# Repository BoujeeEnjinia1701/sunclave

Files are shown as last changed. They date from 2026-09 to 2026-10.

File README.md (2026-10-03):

# SunClave

     

**Area:** BioMedical · **TRL:** 3 of 9 (proof of concept on paper) · **Value-engineering target:** USD 450 (estimated cost USD 528) · **Difficulty:** 3 of 5

Solar concentrator that heats a modified pressure-cooker autoclave, with a calibrated temperature, pressure and time logger that records every cycle.

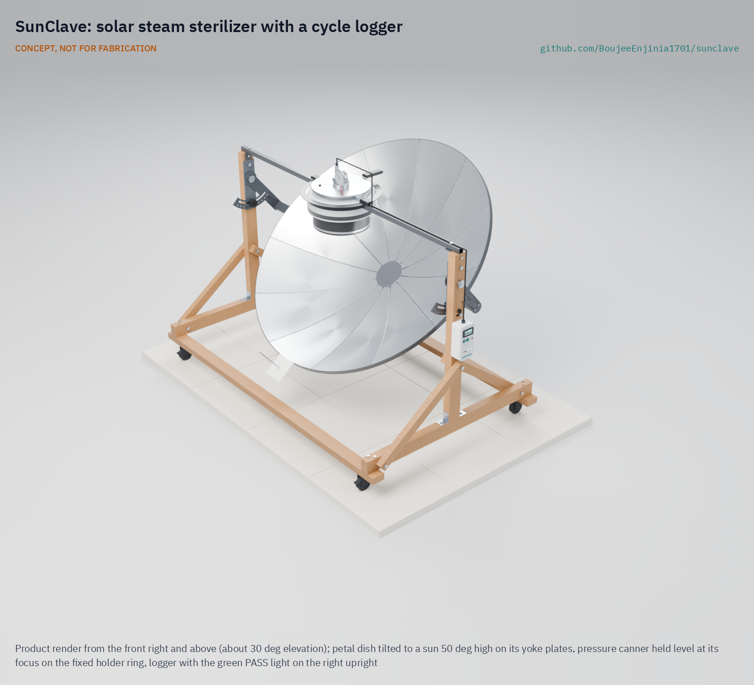
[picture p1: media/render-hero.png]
SunClave: solar steam sterilizer with a cycle logger, product render


[Exploded render](media/render-exploded.png) · [Detail render](media/render-detail.png) · [Interactive 3D model](media/viewer.html) · [Concept blueprint (PDF)](media/concept-blueprint.pdf) · [General arrangement SCL-DWG-001 (PDF)](cad/drawings/SCL-DWG-001.pdf) · [Prototype build plan](docs/05-build-plan.md) · [Design decisions](docs/06-design-decisions.md) · [Calculation note](docs/04-calcs/01-sizing.md) · [Review note](docs/REVIEW.md)

## Concept rationale

A pressure cooker already reaches autoclave conditions, and a 1.4 m solar dish of the kind used for cooking already delivers several hundred watts of heat to a pot. What clinics without power lack is not only the heat but proof that each load was treated, so SunClave pairs a household cooker at the focus of a petal dish with a small logger that checks for saturated steam and times the hold. The cooker stays level while the dish tilts around it, and the operator aims by a shadow, so nobody looks into the focus.

The design is open and garage-buildable because the people who would maintain it are district workshops and biomedical technicians, not a manufacturer's service network. Every structural part is bent flat bar, timber and aluminum sheet joined with bolts and rivets, the only bought pressure part is a commercially rated cooker, and the logger uses common modules. Publishing the geometry, the calculations and the logger's pass criteria lets anyone check the safety case before building one.

## Burning platform

The World Health Organization estimates that close to 1 billion people in low- and lower-middle-income countries are served by health facilities without reliable electricity; in sub-Saharan Africa about 15 % of facilities have no electricity at all and only about 40 % have a reliable supply ([WHO, 2023](https://www.who.int/news-room/fact-sheets/detail/electricity-in-health-care-facilities)). An electric autoclave is out of reach in those facilities, so instruments are boiled, soaked or steamed without any record of the conditions reached.

The consequences show up in infection rates. WHO reports that in low- and middle-income countries 11 % of patients who undergo surgery are infected in the process, and that in Africa up to 20 % of women who have a caesarean section contract a wound infection ([WHO, surgical site infections](https://www.who.int/news-room/questions-and-answers/item/surgical-site-infections)). Instrument reprocessing is one of several links in that chain, and the one that heat plus a record can address directly.

## Where it could be used

As a research and educational prototype, SunClave is a platform for studying off-grid steam sterilization and cycle records; it is not a medical device.

### By industry

| Industry | Use |
| --- | --- |
| Rural primary health care | Research on solar steam cycles and per-load records at health posts without grid power |
| Maternity and midwifery programs | Studying how delivery kits could be reprocessed and logged during daylight |
| Dental and eye outreach | Temporary camps that need instrument reprocessing for a few days at a site |
| Humanitarian and disaster response | Field clinics after grid failures, alongside the stove backup the design already allows |
| Veterinary field practice | Rural livestock and animal-health services reprocessing surgical instruments |
| Biomedical engineering education | Teaching optics, steam thermodynamics, pressure safety and measurement uncertainty on one open design |

### By country or region

| Country or region | Why it matters there |
| --- | --- |
| Kenya and the East African highlands | Highland facilities sit above sea level, where a 103.4 kPa cooker falls short of 121 °C and the logger extends the hold; in sub-Saharan Africa only about 40 % of facilities have reliable electricity ([WHO](https://www.who.int/news-room/fact-sheets/detail/electricity-in-health-care-facilities)) |
| Nepal | Hill and mountain health posts combine altitude with weak grids; about 12 % of health facilities in South Asia have no electricity ([WHO](https://www.who.int/news-room/fact-sheets/detail/electricity-in-health-care-facilities)) |
| Niger (Sahel) | Daily solar irradiation averages about 7 kWh/m², and in 2018 only about 13 % of the population, and about 1 % in rural areas, had access to electricity ([African Development Bank, Desert to Power roadmap for Niger, 2020](https://www.afdb.org/sites/default/files/2024/08/23/desert-to-power_dtp_roadmap_for_niger_en_oct2020.pdf)) |
| Peru and Bolivia (Andes) | In Latin America and the Caribbean about 8 % of health facilities have no electricity and only about 72 % have a reliable supply ([WHO](https://www.who.int/news-room/fact-sheets/detail/electricity-in-health-care-facilities)); highland sites would test the extended-hold method at high altitude |
| Puerto Rico, United States | A high-income case: after Hurricanes Irma and Maria in 2017 it took about 11 months to restore power to all customers in Puerto Rico ([US Government Accountability Office, GAO-19-296](https://www.gao.gov/products/gao-19-296)), a reminder that grid failure also reaches health systems in wealthy economies |

## What sparked the idea

The starting point was two French inventions a year apart. At the 1878 Paris Exposition, Augustin Mouchot won a gold medal for what was then the world's largest parabolic solar collector, which focused sunlight onto a blackened copper vessel of water to raise steam ([Bureau International des Expositions](https://bureauinternationaldesexpositions.bie-paris.org/site/en/latest/blog/entry/expo-1878-paris-the-revelation-of-sun-power)). In 1879 Charles Chamberland, working with Louis Pasteur, introduced the autoclave for medical and scientific use, a descendant of Denis Papin's 1679 high-pressure cooker ([Smithsonian National Museum of American History](https://americanhistory.si.edu/collections/object/nmah_536)). SunClave puts the two back together: a blackened vessel at the focus of a parabolic dish, where the vessel is Papin's pressure cooker doing Chamberland's job, with a logger added so every cycle leaves a record.

## Problem

Rural clinics lack power to sterilize instruments in an autoclave. Close to 1 billion people are served by health facilities with no or unreliable electricity, and where instruments are steamed in a pressure cooker on a fire, nothing records whether each load reached sterilizing conditions. Full problem statement: [docs/01-problem.md](docs/01-problem.md)

## Concept

A 1.4 m parabolic dish of aluminum petals focuses sunlight onto the blackened base of a pressure canner of about 12 L held level at the focus while the dish tilts around it. A cycle logger reads a Pt100 probe in the load zone and an absolute pressure transducer, checks that the chamber holds saturated steam, times the hold and shows PASS or FAIL for each cycle. The TRL 3 calculation note puts about 660 W into the canner at 700 W/m² of direct sun, about 81 min from a cold start to the end of a 30 min hold, and about four cycles on a clear day. Value-engineering target: USD 450. Estimated cost of the constructable design: USD 528 (USD 78 over the target). A 103.4 kPa (15 psi) canner reaches 121 °C only at sea level, so above it the logger extends the hold, records the real temperature and reminds the operator to trim the dish to save water. With Amish's decisions of 2026-09-25 (retarget every 12 min, a 45 kg limit, the whole vessel treated as a marked hot zone, four locking castors and a 0 to 300 kPa transducer), no requirement is missed on paper; cycle time and wind stability remain at risk. Details are in the [review note](docs/REVIEW.md).

Full design precis: [docs/02-concept.md](docs/02-concept.md) · Requirements: [docs/03-requirements.md](docs/03-requirements.md)

## Key components

- 1.4 m petal dish on two yoke plates turning on fixed axles, with two tilt locks and a back-up drop pin, in a bolted timber stand on four locking castors
- Aluminium pressure canner of about 12 L hanging by its handles from a fixed holder ring, with its weighted regulator, factory gauge and relief valve and an insulated jacket; its lid is never drilled
- Pt100 load-zone probe and absolute pressure transducer on a small adapter plate in the lid's vent-pipe hole
- Cycle logger on a USB power bank with pass or fail per cycle, and retarget and trim reminders
- Shadow gnomon for aiming without looking at the sun
- Goggles, a parking cover and keep-out marking for the hot zone

The priced bill of materials is in [bom/bom.csv](bom/bom.csv); the parametric model is `cad/src/model.py`.

## Building the prototype

The design is constructable: every part can be cut, bent, drilled or bought, and every joint is bolted or riveted, with nothing welded. The [prototype build plan](docs/05-build-plan.md) takes a maker through 18 made components and 19 assembly steps, each with a picture drawn from the model, and stops before the cooker is ever pressurised. The changes that made the concept buildable are recorded in [SCL-DDR-003](docs/decisions/0003-design-for-construction.md), and every decision is indexed in the [design decisions register](docs/06-design-decisions.md).

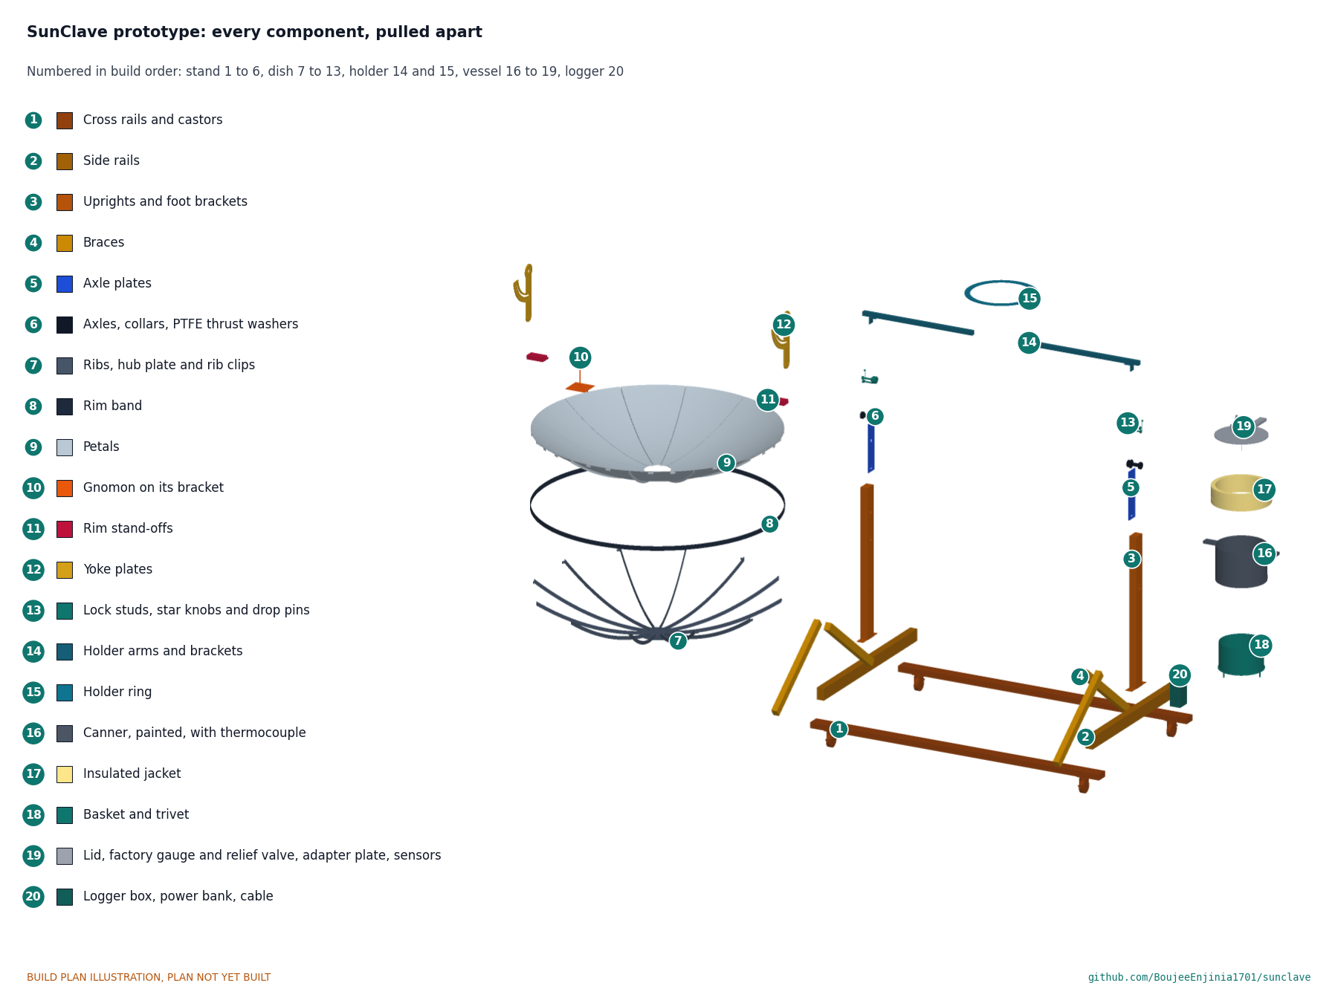
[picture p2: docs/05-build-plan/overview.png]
SunClave prototype: every component, pulled apart and numbered in build order


## Safety

> This is a research and educational prototype. It is not a medical device, has not been cleared or approved by any regulator, and must not be used to diagnose, treat or monitor any person. This design involves concentrated sunlight that can burn skin and eyes and start fires, and heat and pressurized steam. Keep operating pressure and water volume below local boiler and pressure vessel code thresholds, fit a certified relief valve, do not drill the cooker lid (use a pressure canner with factory-fitted gauge and relief valve), and never operate it unattended.

## Repository layout

| Folder | Contents |
| --- | --- |
| `docs/` | Problem, concept, requirements, calculations and design decisions |
| `cad/src/` | build123d Python source, the source of truth for all geometry |
| `cad/step/`, `cad/stl/` | Exported models for FreeCAD, other CAD tools and printing |
| `cad/drawings/` | 2D sketches and dimensioned drawings |
| `bom/` | Bill of materials |
| `electronics/` | KiCad schematics and PCB layouts |
| `firmware/` | Microcontroller code |
| `media/` | Renders, perspectives and photos |
| `build-log/` | Dated prototyping notes |

## Documentation

Controlled documents follow the portfolio [documentation standard](.kit/STANDARDS.md). Each carries a document ID (SCL-PRC-001 for the precis), a version and a revision history. Branded PDFs are built with `python .kit/render.py` and attached to GitHub Releases when a document is tagged, for example `SCL-PRC-001/v1.0`.

## Credits

Designed by Amish Chadha, with contributions from Dr. Geeti Chadha. See [CONTRIBUTORS.md](CONTRIBUTORS.md) for roles. To cite this design, use [CITATION.cff](CITATION.cff) (GitHub shows it as "Cite this repository").

AI assistance (Claude) was used to accelerate concept renders, prototype documentation and first-pass sizing calculations. Design direction and all decisions are Amish Chadha's, recorded in this repository's decision records (`docs/decisions/`).

## Licenses

- **Hardware** (CAD, drawings, BOM, electronics): [CERN-OHL-S v2](LICENSE)
- **Software** (firmware, scripts, notebooks): [MIT](LICENSE-SOFTWARE)

A project of the [Design Molecule](https://designmolecule.com) lab.

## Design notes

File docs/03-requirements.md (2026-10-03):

---
doc_id: SCL-REQ-001
title: SunClave requirements
project: SunClave
doc_type: Requirements
version: "0.8"
status: Draft
date: '2026-10-03'
author: Amish Chadha
license: CERN-OHL-S-2.0
revisions:
- version: "0.1"
  date: '2026-09-24'
  author: Amish Chadha
  change: Initial scaffold
- version: "0.2"
  date: '2026-09-25'
  author: Amish Chadha
  change: First measurable requirements for TRL 2, with design case and status against the concept estimates
- version: "0.3"
  date: '2026-09-25'
  author: Amish Chadha
  change: Apply SCL-DDR-001 (R1, R13 and R17 redefined, design case completed) and replace the status column with the TRL 3 results of SCL-CAL-001
- version: "0.4"
  date: '2026-09-25'
  author: Amish Chadha
  change: Recommendations accepted by Amish (DDR-002)
- version: "0.5"
  date: '2026-10-01'
  author: Amish Chadha
  change: Status from SCL-CAL-001 v0.3 for the constructable design (SCL-DDR-003); R17 reported against the value-engineering target
- version: "0.6"
  date: '2026-10-02'
  author: Amish Chadha
  change: "R15 note: back-up drop pin decided on 2026-10-02 (SCL-DEC-001); no requirement changed status"
- version: "0.7"
  date: '2026-10-02'
  author: Amish Chadha
  change: "Status from SCL-CAL-001 v0.4 (canner, adapter plate and drop pins carried into the design); R8 wording for the factory relief valve; no requirement changed status"
- version: "0.8"
  date: '2026-10-03'
  author: Amish Chadha
  change: "R16 mass margin of 0.2 kg accepted by Amish on 2026-10-03; weighed at TRL 4 with a canner of 5.0 kg or less"
---

# SunClave requirements

These requirements are checked by calculation in SCL-CAL-001 at TRL 3. Targets are still proposals, not yet validated with users, and will be revised after co-design sessions (see SCL-PRB-001). R1, R13 and R17 were restated on 2026-09-25 to apply Amish's decisions in SCL-DDR-001 (altitude option B, and the budget cuts and $450 budget). In v0.4, R10, R11, R14 and R16 are restated or relaxed and R12's design basis changed, applying Amish's acceptance of the recommendations in SCL-DDR-002. The status column gives the TRL 3 result from SCL-CAL-001 v0.3, for the constructable design of SCL-DDR-003; every value is a paper estimate. The cost target in R17 is a value-engineering target (Amish, 2026-10-01), so R17 is reported as over or under it rather than as met or not met.

The **design case** is a clear day with 700 W/m² direct normal irradiance (DNI) and the sun 60° above the horizon, 25 °C ambient, wind 2 m/s (below 3 m/s), a site at sea level, and a load of 2.0 kg of unwrapped or single-wrapped solid stainless instruments in a 0.5 kg basket, with 1.5 L of water in a 12 L aluminum cooker.

> **Safety:** These requirements describe a pressure vessel heated by concentrated sunlight, in a research and educational prototype that is not a medical device. R8 to R11 are safety requirements and take precedence over throughput and cost. A PASS against R1 and R12 records conditions; it does not prove sterility.

| ID | Requirement | Target | Verification (TRL 3 or later) | TRL 3 status (SCL-CAL-001) |
| --- | --- | --- | --- | --- |
| R1 | Sterilizing condition (redefined 2026-09-25, SCL-DDR-001 item 1) | Saturated steam in the load zone for an exposure equal to 20 min (unwrapped) or 30 min (wrapped) at 121 °C, using z = 10 °C for any lower temperature; never below 115 °C nor above 124 °C in normal operation; the real temperature and hold are recorded and a cycle below 121 °C is never labeled 121 °C | Calculation; later instrumented cycles with biological indicators | **Not verifiable at TRL 3.** Met by calculation to 2,400 m (120.95 °C and 30.3 min at sea level; 117.7 °C and 63 min at 1,800 m), but the equivalence needs biological-indicator evidence |
| R2 | Load capacity | Basket at least 250 mm diameter by 150 mm deep; 2.0 kg of solid instruments per cycle (about two delivery kits or four suture kits) | Model check | Met: 250 x 150 mm basket in a 12.3 L cooker, 16 mm above the water |
| R3 | Load type | Solid instruments only, unwrapped or single-wrapped in porous wrap; no lumened, hollow or textile loads | Instructions and design review | Met by definition (decided, SCL-DDR-001 item 9) |
| R4 | Cycle time | Cold start to end of hold in 90 min or less in the design case | Energy calculation; later timed cycles | **At risk:** about 81 min central, 72 to 111 min across scenarios |
| R5 | Daily throughput | 3 or more complete cycles on a clear day (DNI 600 W/m² or more from 09:00 to 15:00 solar time) | Energy calculation | Met: 4 cycles in each case checked; zero on overcast days |
| R6 | Cycle record | Load-zone temperature and chamber pressure logged at 1 s intervals from start to end; cycle ID, date and time, hold duration, minimum hold temperature, equivalent exposure and a pass or fail flag stored for 1,000 or more cycles and shown to the operator at cycle end | Design review; later bench test | Met by design: about 173 kB per cycle, about 23,000 cycles on 4 GB |
| R7 | Measurement accuracy | Temperature within 0.5 °C at 121 °C; pressure within 5 kPa; field check against boiling water at each site | Component datasheets; calibration method at TRL 3 | Met on datasheets: 0.44 °C with a 0.05 % reference resistor; 3 kPa with the 0 to 300 kPa transducer. The field check needs a reference barometer |
| R8 | Pressure safety | Working pressure 103.4 kPa (15 psi) gauge set by the vessel's regulator; a relief valve set at 125 kPa gauge or less (since 2026-10-02 the canner's factory relief valve); the vessel's own overpressure plug retained; vessel rated by its maker for the working pressure | Design review; relief capacity calculation | Met: factory relief valve 5.2 times and vent 2.7 times the worst steam generation if its seat is 4 mm or more; the adapter plate's bore round the probe equals a 5.2 mm hole; lid not drilled; vessel rating and relief valve to confirm for the chosen model |
| R9 | Heat input control | Operator can stop heat input within 10 s by turning the dish off the sun, and the dish is shaded when parked | Design review | Met: below 5 % of power at 15° off the sun; parking cover in the BOM |
| R10 | Boil-dry protection (restated 2026-09-25, SCL-DDR-002 item 17) | At least 0.5 L of water left at the end of a cycle in the design case, and at any altitude to 2,400 m in 1,000 W/m² sun when the operator follows the trimming rule; logger shows a trim reminder whenever the computed hold exceeds 40 min; logger alarm if base temperature exceeds 140 °C | Water budget; later test | Met: 1.26 L left in the design case; with trimming 1.31 L at 1,800 m and 1.28 L at 2,400 m (0.15 L at 1,800 m untrimmed). Depends on the operator following the reminder |
| R11 | Burn and glare protection (restated 2026-09-25, SCL-DDR-002 item 15) | The whole pressure vessel and its fittings are a hot zone, like the lid, reached only after the dish is turned at least 15° off the sun (R9); the focus is reached only through the dish, so no physical guard; parking cover and eye protection supplied; a keep-out marked on the ground around the dish and vessel | Design review | Met by design review: parking cover, two pairs of goggles and keep-out marking in the BOM (items 19 to 21) |
| R12 | Air removal check | Logger flags any hold where measured temperature is more than 2 °C below the saturation temperature for the measured pressure | Calculation; later test with deliberate air leak | Met, narrowly: check uncertainty 0.64 °C with the 0 to 300 kPa transducer (SCL-DDR-002 item 18), 32 % of the threshold; sure to flag about 8 % air |
| R13 | Off-grid logger power (redefined 2026-09-25, SCL-DDR-001 item 2) | Logger runs 3 or more days on its own USB power bank without recharging; the bank recharges from any USB source and does not switch off at the logger's low current | Power budget | Met: about 8.7 days |
| R14 | Tracking effort (relaxed 2026-09-25, SCL-DDR-002 item 13) | Retarget no more often than every 12 min, with a logger reminder at each interval; aim by a shadow gnomon without looking at the sun or the focus | Optics calculation | Met: power stays within 10 % of on-target for about 13 min |
| R15 | Stability | Does not tip in a 10 m/s wind with the dish at any tilt and the cooker loaded | Moment calculation | **At risk:** tipping factor 1.40 at 15° elevation. Four locking castors (SCL-DDR-002 item 16) grip 237 N against 153 N of wind; park the dish face-up in high wind. A back-up drop pin through the yoke plate fans stops a slipping tilt lock (decided 2026-10-02) |
| R16 | Portability and build (relaxed 2026-09-25, SCL-DDR-002 item 14) | Total mass 45 kg or less; separates into pieces of 20 kg or less; built with hand tools, a drill and bolted joints | Mass estimate; model check | Met: about 44.8 kg empty (0.2 kg margin; accepted by Amish on 2026-10-03; weighed at TRL 4 with a canner of 5.0 kg or less, SCL-DDR-003 A1); the bolted stand comes apart, largest piece 15.3 kg |
| R17 | Cost (redefined 2026-09-25, SCL-DDR-001 item 2; a value-engineering target, 2026-10-01) | Parts for one prototype against a value-engineering target of USD 450, validation consumables excluded | Priced BOM (`bom/bom.csv`) | Value-engineering target: USD 450. Estimated cost of the constructable design: USD 528 (USD 78 over the target) |

## Requirements not met or at risk

No requirement is now not met. Before SCL-DDR-002, R11, R14 and R16 were not met; they are met because their targets were restated or relaxed on Amish's acceptance of the recommendations, not because the design improved. R10 and R12 moved from at risk to met through the trimming rule and the 0 to 300 kPa transducer.

- **R4 cycle time (at risk).** Met in the central case (81 min), missed in the unfavourable one (111 min).
- **R15 stability (at risk).** Thin tipping margin at low sun (factor 1.40); the four locking castors now stop the stand rolling.
- **R16 mass (met, thin margin).** 44.8 kg against 45 kg after the constructable design added clips, plates, brackets and bolts, and the canner, adapter plate and drop pins added 0.4 kg; Amish accepted the margin on 2026-10-02 and again on 2026-10-03 ("TIght Margins - i accept the margins"), to be checked by weighing at TRL 4 with a canner of 5.0 kg or less.
- **R17 cost.** USD 78 over the value-engineering target; the cost drivers and savings worth trying are in the design decisions register (SCL-DEC-001).
- **R1 sterilizing condition (not verifiable at TRL 3).** The equivalent-exposure method needs biological indicators.

## Assumptions

- Dish aperture 1.4 m (1.539 m²), focal length 500 mm, reflectance 0.85, slope error 10 mrad, absorber absorptance 0.92; optics by ray trace in SCL-CAL-001.
- Saturated steam temperatures from IAPWS-IF97; ICAO standard atmosphere for ambient pressure with altitude.
- Hold times follow CDC Table 7 and the IARC manual cited in SCL-PRB-001. Equivalent hold at lower temperature uses a z-value of 10 °C, which is a common engineering assumption and not a validated claim.
- "Pass" in R6 means the recorded cycle met R1 and R12. It does not prove sterility; biological and chemical indicators remain the reference.

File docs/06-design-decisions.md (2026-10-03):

---
doc_id: SCL-DEC-001
title: SunClave design decisions register
project: SunClave
doc_type: Design decisions register
version: "0.4"
status: Draft
date: '2026-10-03'
author: Amish Chadha
license: CERN-OHL-S-2.0
revisions:
- version: "0.1"
  date: '2026-10-01'
  author: Amish Chadha
  change: Register opened with the open decisions from the TRL 2 and TRL 3 reviews and the design-for-construction work, items to confirm, value engineering and decisions made
- version: "0.2"
  date: '2026-10-02'
  author: Amish Chadha
  change: Amish approved the recommendations for open decisions 1 to 5 (lid fittings decided; SCL-DDR-003 accepted with a back-up drop pin); moved to decisions made
- version: "0.3"
  date: '2026-10-02'
  author: Amish Chadha
  change: "Canner, adapter plate and drop pins priced and carried into the design; value engineering and items to confirm updated"
- version: "0.4"
  date: '2026-10-03'
  author: Amish Chadha
  change: "Amish accepted the R16 mass margin of 0.2 kg on 2026-10-03, to be weighed at TRL 4 with a canner of 5.0 kg or less; row added to decisions made"
---

# SunClave design decisions register

Every design decision still to be made, and every decision made, in one place. Each decision is argued in full in its decision record under `docs/decisions/`; this register is the index Amish works from. The build plan (`docs/05-build-plan.md`) describes the design as it stands and does not list open decisions.

> **Safety:** SunClave is a research and educational prototype, not a medical device. Decision 1 below is a pressure-safety decision and must be made before the cooker is ever pressurised with the fittings on its lid.

## Open decisions

None. All open decisions were decided on 2026-10-02.

## To confirm when parts are bought

| # | What to confirm | Why it matters | Source |
| --- | --- | --- | --- |
| 1 | The canner's maker's rating for 103.4 kPa, its outside diameter (about 288 mm), its mass with fittings (about 4.8 kg, 5.0 kg at most), and handles whose undersides are about 28 mm below the rim and reach at least 214 mm from the centre | The rating is R8; the handles must rest on the 408 mm holder ring and the jacket must clear its 348 mm hole; the mass margin of R16 is 0.2 kg | SCL-DDR-001 items 4 and 5, SCL-DDR-003 C3 |
| 2 | The reflector sheet takes a 12 mm flange fold without cracking its bright layer | The petals are fixed by riveting through these flanges | SCL-DDR-003 C6 |
| 3 | A 20 x 3 mm bar bends on edge in the plywood jig without buckling (bend one rib first) | If it buckles, the ribs need a heavier bar or a fabricator's rolls | SCL-DDR-003 C6 |
| 4 | Castor mounting height 102 mm and a top-plate hole pattern on a 42 mm square, all four with brakes | Sets the stand height and the drilling of the cross rails | SCL-DDR-003 C5 |
| 5 | The power bank has a low-current (always-on) mode | The logger draws about 72 mA; many banks switch off below 50 to 100 mA | SCL-CAL-001 section 11 |
| 6 | The canner's factory relief valve has a seat of 4 mm or more and a set pressure of 125 kPa gauge or less; the lid's vent-pipe hole and thread, for the adapter plate | R8 relief capacity; the adapter plate is made to fit the canner | SCL-CAL-001 section 8 |
| 7 | The pressure transducer's overpressure rating is 600 kPa or more | It must survive a relief lift | SCL-DDR-002 item 18 |

## Value engineering

Value-engineering target: USD 450 (a hypothetical control target, not a limit). Estimated cost of the constructable design: USD 528 (USD 78 over the target), validation consumables (USD 45) excluded. Main cost drivers and savings worth trying:

- The largest lines are the pressure canner with its gauge and relief valve (USD 100), the reflector petals (USD 75), the cycle logger (USD 66), the timber stand with castors, axles and plates (USD 58) and the adapter plate, gland and probe (USD 45).
- Making the design constructable added USD 57 (from USD 440): the yoke plates, stand-offs and locks (line 3, USD 18 to 30), the stand's axle plates, axles, collars and brackets (line 4, USD 44 to 58), the clips (line 2), the plate ring and brackets (line 5), the larger logger box and plug-in sensor leads (line 14) and more bolts (line 17).
- The decisions of 2026-10-02 added USD 31 (from USD 497): the pressure canner sold with its gauge and relief valve (line 6, USD 55 to 100) in place of the household cooker and the separate gauge and relief valve (lines 8 and 9, USD 35, now supplied with the canner), the vent-stem adapter plate (line 10, USD 30 to 45) and the drop pins and lanyards (line 3, USD 30 to 36).
- Savings worth trying: compare canners sold with a gauge in the target area, since line 6 is now the largest line; have one local cutting shop cut the yoke plates, axle plates, holder ring and hub plate from one sheet of steel (likely cheaper than four separate jobs); price aluminised film on plain 0.5 mm aluminium against bright reflector sheet; buy the logger modules as one combined board; buy bolts in boxes of 50 rather than by the piece.

## Decisions made

| Date | Decision | Decided by | Record |
| --- | --- | --- | --- |
| 2026-09-25 | TRL 2 review items 1 to 4 and 6 to 11: altitude option B, budget cuts with USD 450, pitch wording, 12 L household cooker, level cooker at the focus, petal dish, gnomon aiming, load limits, logger pass criteria, backup heat | Amish: "proceed with all of your recommendations across all batches. Make sure we don't proceed to TRL 4 on any of them." | SCL-DDR-001 |
| 2026-09-25 | Items 13 to 18: retarget every 12 min, 45 kg total, whole vessel a marked hot zone, four locking castors, trimming rule, 0 to 300 kPa transducer | Amish: "i accept all your recommendations, go with them across all repos." | SCL-DDR-002 |
| 2026-09-25 | TRL 4 is on hold for the whole portfolio | Amish: "Make sure we don't proceed to TRL 4 on any of them" | SCL-DDR-001 |
| 2026-09-30 | Make the design physically buildable while drawing the build plan | Amish: "If you are realising that the design cannot be built as per concept - fix the design assumptions to match and be physically feasible as you draw the illustrations." | SCL-DDR-003 (accepted on 2026-10-02, below; was open for review as decision 2) |
| 2026-09-30 | Open decisions are kept in this register, not in the build plan | Amish: "don't log outstanding decisions in this build plan - that is not the place for it." | This register |
| 2026-10-01 | `budget_usd` is a value-engineering target, not a limit | Amish: "the budgets are a hypothethical control target to ensure we are thinking along a value engineering lens." | This register, Value engineering |
| 2026-10-02 | Lid fittings: the maker's lid is not drilled; a pressure canner sold with a factory gauge and relief valve is used, and the probe gland goes on an adapter plate on the vent stem that keeps a bore of 3 mm or more and leaves the overpressure plug untouched; a lid is drilled only with the maker's written approval | Amish: "i approve your recommendations for all 555 open decisions." | SCL-DDR-001, item 5 |
| 2026-10-02 | Design for construction accepted: the changes C1 to C9, as made, with the tilt lock settled under decision 4 | Amish: "i approve your recommendations for all 555 open decisions." | SCL-DDR-003, Table 1 |
| 2026-10-02 | R16 mass margin of 0.6 kg accepted; the prototype is weighed at TRL 4, with the 5 mm yoke plates and lighter holder arms ready | Amish: "i approve your recommendations for all 555 open decisions." | SCL-DDR-003, A1 |
| 2026-10-02 | Tilt lock: the two friction locks are kept for aiming and a drop pin through a row of holes in the fan is added as a back-up stop; the pin is removed only if the TRL 4 slip test shows the locks holding at least twice the 45 N·m worst torque | Amish: "i approve your recommendations for all 555 open decisions." | SCL-DDR-003, A2 |
| 2026-10-02 | First partner to approach: a university biomedical or global health engineering group with an established rural clinic partner in a sunny region below 2,400 m, for example through an Engineering World Health university chapter | Amish: "i approve your recommendations for all 555 open decisions." | SCL-DDR-001, item 12 |
| 2026-10-03 | R16 mass margin of 0.2 kg accepted (about 44.8 kg against 45 kg); the prototype is weighed at TRL 4 with a canner of 5.0 kg or less | Amish: "TIght Margins - i accept the margins" | SCL-REQ-001, R16; SCL-DDR-003, A1; [REVIEW.md](REVIEW.md), session 2026-10-03 |

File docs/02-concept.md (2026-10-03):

---
doc_id: SCL-PRC-001
title: SunClave design precis
project: SunClave
doc_type: Design precis
version: "0.7"
status: Draft
date: '2026-10-02'
author: Amish Chadha
license: CERN-OHL-S-2.0
revisions:
- version: "0.1"
  date: '2026-09-24'
  author: Amish Chadha
  change: Initial scaffold
- version: "0.2"
  date: '2026-09-25'
  author: Amish Chadha
  change: Populate to TRL 2 (architecture, components, first-order numbers, altitude finding, safety, media)
- version: "0.3"
  date: '2026-09-25'
  author: Amish Chadha
  change: Apply SCL-DDR-001 decisions (option B, $450 budget and cuts, vessel, holder, dish, aiming, load limits, pass criteria, backup heat); replace first-order numbers with SCL-CAL-001; TRL 3 model, drawing and media
- version: "0.4"
  date: '2026-09-25'
  author: Amish Chadha
  change: Recommendations accepted by Amish (DDR-002)
- version: "0.5"
  date: '2026-10-01'
  author: Amish Chadha
  change: Constructable design (SCL-DDR-003, draft) and build plan SCL-BLD-001; numbers from SCL-CAL-001 v0.3; cost against the value-engineering target
- version: "0.6"
  date: '2026-10-02'
  author: Amish Chadha
  change: "Decisions of 2026-10-02 carried in: lid fittings (no drilling; pressure canner with factory gauge and relief valve), back-up drop pin, first partner to approach"
- version: "0.7"
  date: '2026-10-02'
  author: Amish Chadha
  change: "Canner, vent-stem adapter plate and drop pins carried into the model, BOM and calculations (SCL-CAL-001 v0.4); components and headline results updated"
---

# SunClave design precis

SunClave is a 1.4 m parabolic dish of aluminum petals that focuses sunlight onto the blackened base of a pressure canner of about 12 L held level at the focus, with a cycle logger that measures temperature in the load zone and chamber pressure and flags each cycle as pass or fail. The TRL 3 calculations (SCL-CAL-001) put about 660 W into the canner on a clear day, enough to go from cold to the end of a 30 min hold in about 81 min and to run about four cycles between 09:00 and 15:00. On 2026-09-25 Amish accepted the recommendations on the TRL 3 findings (SCL-DDR-002): the dish is retargeted every 12 min, the mass limit is 45 kg, the whole vessel is treated as a marked hot zone instead of guarding the focus, all four castors lock, a trimming rule protects the water at altitude and the pressure transducer spans 0 to 300 kPa. On paper no requirement is now missed; cycle time (R4) and wind stability (R15) remain at risk. On 2026-10-01 the design was made constructable (SCL-DDR-003, accepted by Amish on 2026-10-02): every part can be cut, bent, drilled or bought and every joint is bolted or riveted, and the prototype build plan (SCL-BLD-001) shows how. On 2026-10-02 Amish decided the lid fittings (a canner with its own gauge and relief valve, the lid never drilled, the probe and pressure sensor on a vent-stem adapter plate) and a back-up drop pin for the tilt locks; both are now in the model. Value-engineering target: USD 450. Estimated cost of the constructable design: USD 528 (USD 78 over the target).

> **Safety:** SunClave is a research and educational prototype, not a medical device. It has not been cleared or approved by any regulator and must not be relied on to sterilize instruments used on patients. It combines concentrated sunlight that can burn skin, blind and start fires, with a pressure vessel holding steam at about 121 °C (250 °F). See the safety section before building or operating anything.

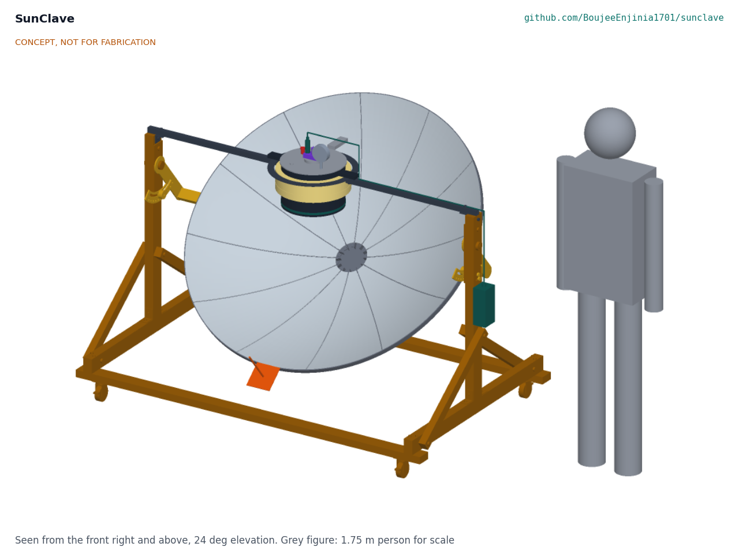
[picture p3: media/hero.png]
Hero render


*Figure 1. SunClave with the dish aimed at a sun 50 degrees above the horizon, and a 1.75 m person for scale. The cooker is held level at the focus on a holder fixed to the stand; the dish and yoke tilt about it.*

## How it works

1. **Load.** The operator puts 1.5 L of water in the cooker, sets cleaned instruments in the basket on its trivet above the water, closes the lid and sets the cooker in the level holder at the focus.
2. **Aim.** The operator unlocks the four castors, turns the stand to face the sun, locks them again and tilts the dish until the shadow of the sighting gnomon falls on the center of its target. Nobody needs to look at the sun or at the bright focus. The logger sounds a reminder every 12 min, and retargeting at that interval keeps the absorbed power within 10 % of on-target (SCL-CAL-001 section 3; decided, SCL-DDR-002 item 13).
3. **Heat and purge air.** About 660 W is absorbed by the blackened base and the black band of wall above it. The water boils, and steam leaves through the open vent for at least 5 min to push air out of the chamber before the weighted regulator is fitted. The logger recognizes this purge as a plateau at the local boiling point.
4. **Pressurize and hold.** With the regulator fitted, pressure rises to 103.4 kPa gauge and the regulator vents the excess. The hold is 20 min (unwrapped) or 30 min (wrapped) at sea level, and longer above it (decided option B): the logger computes the hold that gives the same exposure as 121 °C with z = 10 °C and records the real temperature. Whenever the computed hold exceeds 40 min (every site at 1,000 m and above), the logger shows a trim reminder and the operator trims the dish off the sun until the regulator only just vents, which keeps at least 0.5 L of water in strong sun up to 2,400 m (decided, SCL-DDR-002 item 17).
5. **Record.** Throughout, the logger reads a Pt100 probe in the load zone and an absolute pressure transducer on the lid. It checks that the load-zone temperature matches the saturation temperature for the measured pressure (air left in the chamber shows up as a lower temperature), times the hold, and at the end shows PASS or FAIL with a cycle number to copy into the register.
6. **Cool and unload.** The operator turns the dish away from the sun, fits the parking cover if the session is over, lets the pressure fall to zero on the gauge (about 10 min), removes the regulator, opens the lid and lets the load dry in the residual heat.

On cloudy days the same cooker runs on a wood, charcoal or LPG stove and is logged the same way (decided, SCL-DDR-001 item 11).

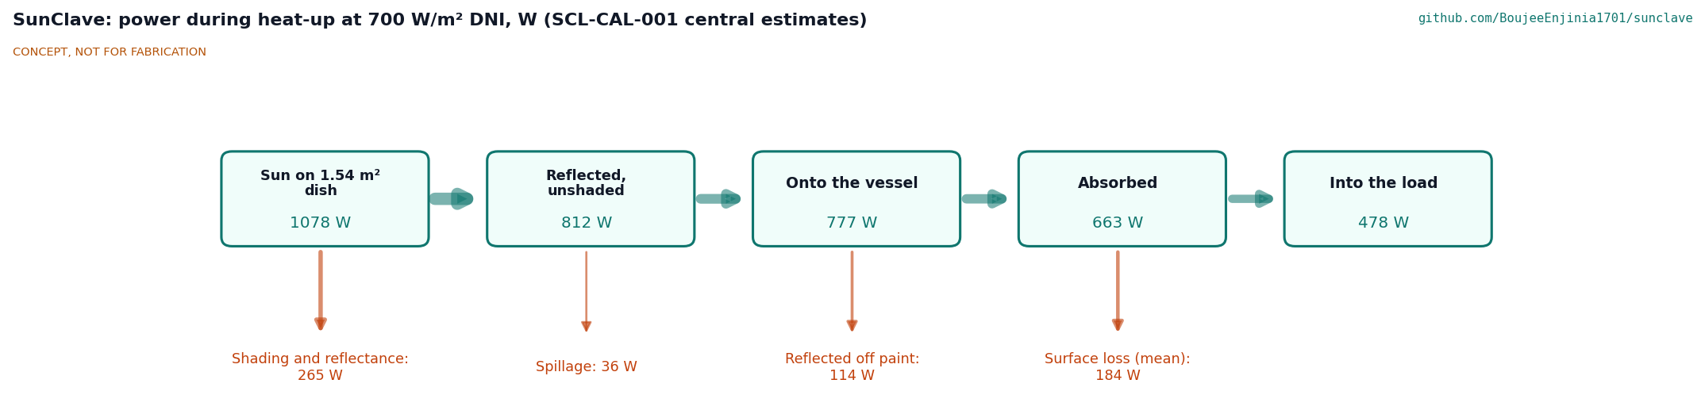
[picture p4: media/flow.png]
Energy flow


*Figure 2. Power flow during heat-up at 700 W/m² DNI and a sun 60° high, central estimates from SCL-CAL-001.*

## Main components

Numbers match the exploded view (Figure 3) and `bom/bom.csv`. The general arrangement is drawing SCL-DWG-001 (`cad/drawings/`), generated from `cad/src/model.py`.

| # | Component | Choice | Notes |
| --- | --- | --- | --- |
| 1 | Reflector | 12 petals of polished aluminum sheet 0.5 mm, 1.4 m aperture, focal length 500 mm | SK14-style petal layout (decided) |
| 2 | Dish ribs, rim, hub and clips | Twelve 20 x 3 mm steel flat-bar ribs bent on edge, 25 x 4 mm rim band, 200 mm hub plate, 24 angle clips; petals riveted through their folded flanges | Holds the petal shape (SCL-DDR-003) |
| 3 | Tilt yoke and locks | A 6 mm steel yoke plate each side turning on a fixed 20 mm axle, joined to the rim band by a tube stand-off; a fan on each plate with a slot that a star knob clamps; a drop pin on a lanyard through a row of holes in each fan as a back-up stop | Dish-axis elevation 15 to 90 degrees; the two locks hold up to about 45 N·m of gravity torque (SCL-DDR-003); if a lock slips the pin stops the dish within 7.5 degrees (decided 2026-10-02) |
| 4 | Stand with castors | Bolted treated timber: cross rails, side rails on edge, uprights to 1.10 m and lapped braces; steel axle plates and axles; four locking castors | Timber decided to save cost (SCL-DDR-001 item 2); all four castors lock (SCL-DDR-002 item 16); azimuth by turning the whole stand |
| 5 | Level pot holder | Flat steel ring the body handles rest on, on two tube arms carried on the upright tops | Fixed to the stand: the loaded canner's centre of mass is about 96 mm above the axis, so a swinging holder would be top-heavy |
| 6 | Pressure canner | Aluminum pressure canner of about 12 L sold with a factory gauge and relief valve, about 280 mm inside diameter x 200 mm deep, 103.4 kPa weighted regulator, overpressure plug; base and lowest 80 mm of wall painted matte black | Vessel decided (SCL-DDR-001 item 4); a canner with factory fittings since 2026-10-02 (item 5) |
| 7 | Lid with regulator | Supplied with item 6; carries items 8 and 9 as supplied and the adapter plate (item 10) in its vent-pipe hole | The lid is not drilled: the factory gauge and relief valve stay as supplied, and the probe gland goes on an adapter plate on the vent stem with a bore of 3 mm or more, overpressure plug untouched (decided 2026-10-02, item 5) |
| 8 | Pressure gauge (factory-fitted) | The canner maker's dial gauge, as supplied | Reads without power, independent of the logger; checked against a reference before use |
| 9 | Relief valve (factory-fitted) | The canner maker's relief valve; set 125 kPa gauge or less and seat 4 mm or more to confirm | Passes 5.2 times the worst steam generation if its seat is 4 mm or more |
| 10 | Vent-stem adapter plate, gland and Pt100 probe | Stainless plate in the lid's vent-pipe hole carrying the maker's vent pipe, the transducer and a compression gland for a 3 mm class A Pt100 into the load zone; 6 mm bore round the probe | Measures where the instruments are; the vent stays as open as a 5.2 mm hole; no new hole in the lid |
| 11 | Insulated jacket | 25 mm mineral wool with aluminized skin on the upper wall | Black band and base stay bare to take the focus |
| 12 | Water charge | 1.5 L per cycle | About 1.26 L left after a central sea-level cycle |
| 13 | Instrument basket and trivet | Stainless basket 250 mm diameter x 150 mm deep on a 40 mm trivet | Resized from 270 x 180 mm, which did not fit a 12 L cooker |
| 14 | Cycle logger | ESP32-class board, Pt100 interface with 0.05 % reference, 16-bit ADC, 0 to 300 kPa absolute pressure transducer, base-edge thermocouple, RTC, microSD, OLED display, buzzer | 1 s logging, pass or fail per cycle, boil-dry alarm, 12 min retarget reminder, trim reminder for holds over 40 min; OLED decided to save cost; transducer span decided (SCL-DDR-002 item 18) |
| 15 | Logger power bank | 10,000 mAh USB bank with a low-current mode, kept in the shaded logger box | About 8.7 days per charge; replaces the panel and cell (decided) |
| 16 | Sighting gnomon | Pin parallel to the dish axis over a target plate, on a bracket outside the rim band | Aiming by shadow (decided) |
| 19 | Eye protection | Two pairs of shade 5 goggles | Added for R11 |
| 20 | Parking cover | Opaque cover for the dish | Added for R9 and R11 |
| 21 | Keep-out marking | Barrier tape and four ground pegs marking 2 m around the dish and vessel | Added for the restated R11 (SCL-DDR-002 item 15) |

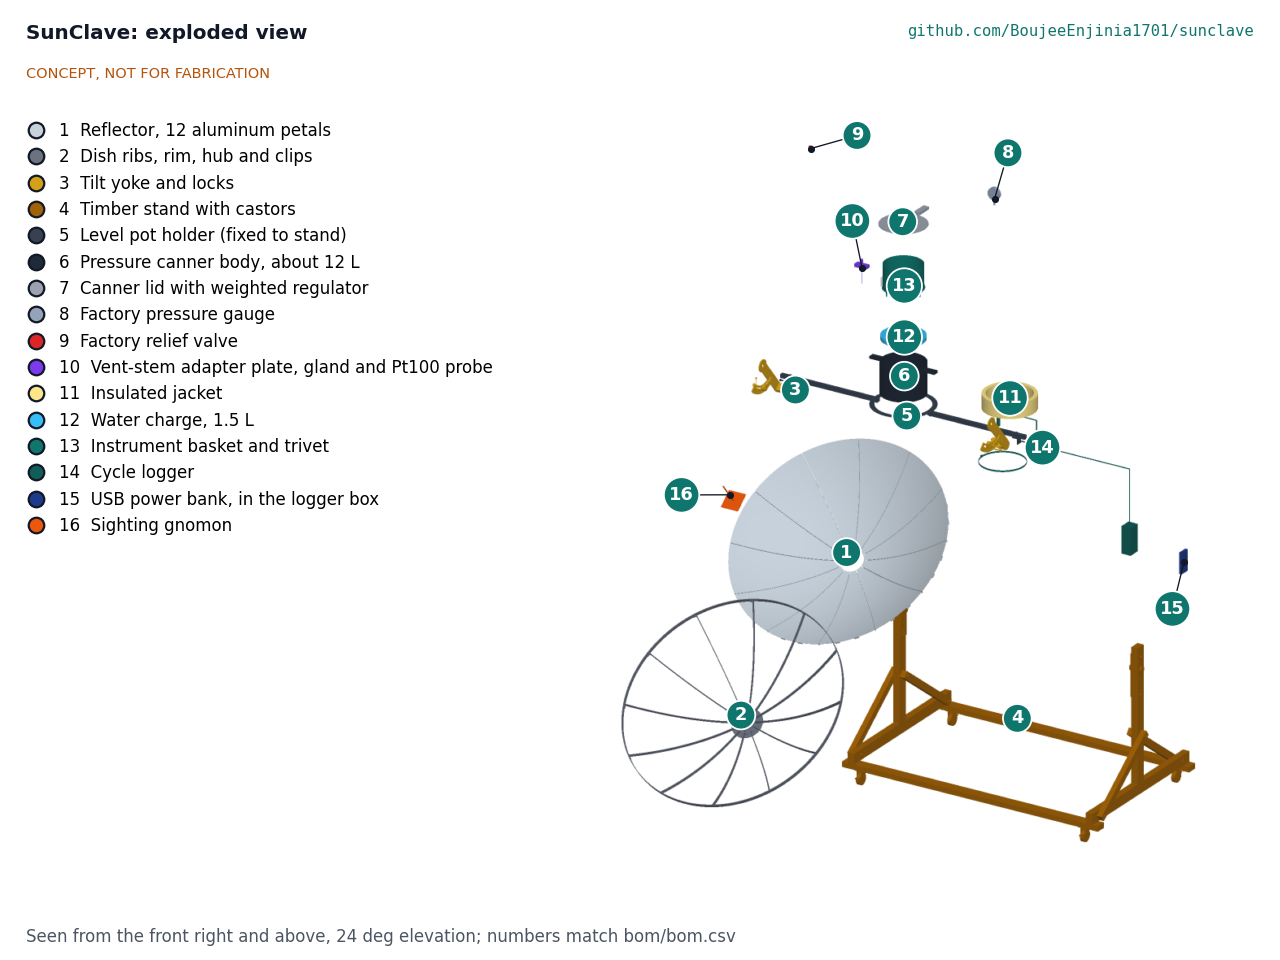
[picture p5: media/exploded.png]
Exploded view


*Figure 3. Exploded view with numbered callouts matching the BOM. The cooker parts are lifted out along the vertical axis. Items 17 to 21 are not modelled.*

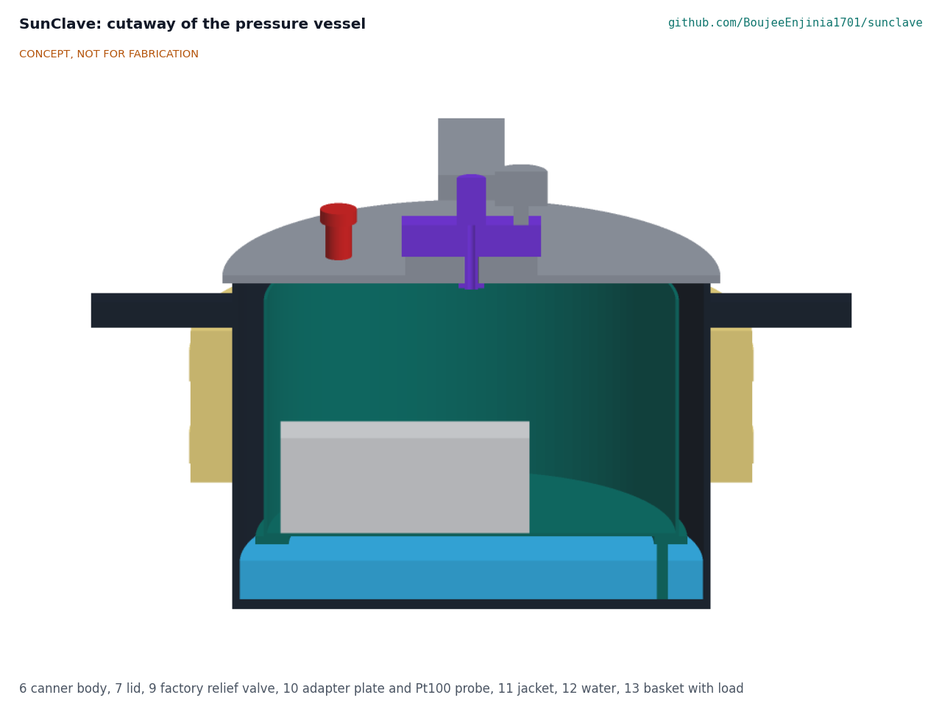
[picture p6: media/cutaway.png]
Cutaway


*Figure 4. Section through the pressure vessel: water below the trivet, the basket and instrument load in steam, the Pt100 probe reaching into the load zone, and the jacket on the upper wall above the bare black band.*

## Key numbers (TRL 3)

All values are paper estimates from SCL-CAL-001 (`python docs/04-calcs/sizing.py`) for the design case in SCL-REQ-001 v0.5: 700 W/m² DNI, sun 60° high, 25 °C, wind 2 m/s, sea level, 2.0 kg of instruments, 1.5 L of water.

*Table 1. Headline results, central case unless a range is given.*

| Quantity | Value | Requirement |
| --- | --- | --- |
| Sun on the aperture | 1,078 W (1.539 m²) | |
| Absorbed by the canner | 663 W on target (575 to 716 W across scenarios); 555 W at 15° sun, 733 W overhead | |
| Peak flux on the base | about 270 kW/m² in the hottest 20 mm cell; mean 11 kW/m² | |
| Heat loss at 121 °C | 395 W (black base and band 245 W, lid 101 W) | |
| Cold start to end of 30 min hold | 81 min (72 to 111 min) | R4 at risk |
| Cycles, 09:00 to 15:00 | 4 | R5 met |
| Water left after a 30 min hold | 1.26 L; with the trimming rule 1.31 L at 1,800 m in strong sun (0.15 L untrimmed) | R10 met (restated) |
| Steam temperature at 103.4 kPa gauge | 120.95 °C at sea level; 117.7 °C at 1,800 m (hold 63 min) | R1 not verifiable at TRL 3 |
| Temperature and pressure accuracy | 0.44 °C; 3 kPa | R7 met |
| Air-removal check uncertainty | 0.64 °C against a 2 °C threshold (0 to 300 kPa transducer) | R12 met, narrowly |
| Retarget interval for 90 % of on-target power | about 13 min, against a 12 min target | R14 met (relaxed) |
| Relief valve capacity | 5.2 times the worst steam generation | R8 met |
| Tipping factor at 10 m/s | 1.40 at 15° sun; four locked castors grip 237 N against 153 N | R15 at risk |
| Mass, empty | 44.8 kg against 45 kg; largest piece 15.3 kg | R16 met (relaxed), thin margin |
| Logger autonomy | 8.7 days | R13 met |
| Parts cost | USD 528 against a USD 450 value-engineering target (USD 78 over) | R17 reported against the target |

### Altitude and sterilizing temperature

A weighted regulator holds a fixed pressure **above ambient**, so the steam temperature falls with altitude. Under the decided option B the logger extends the hold to give the same exposure as 121 °C with z = 10 °C, and records the real temperature.

*Table 2. Steam temperature and extended hold with altitude (IAPWS-IF97, standard atmosphere).*

| Altitude | Ambient pressure | Steam temperature at 103.4 kPa gauge | Gauge pressure needed for 121 °C | Hold for 20 / 30 min at 121 °C (z = 10 °C, not validated) |
| --- | --- | --- | --- | --- |
| 0 m | 101.3 kPa | 120.95 °C | 103.7 kPa | 20 / 30 min |
| 500 m | 95.5 kPa | 120.03 °C | 109.6 kPa | 25 / 37 min |
| 1,000 m | 89.9 kPa | 119.13 °C | 115.2 kPa | 31 / 46 min |
| 1,500 m | 84.6 kPa | 118.26 °C | 120.5 kPa | 38 / 56 min |
| 1,800 m | 81.5 kPa | 117.75 °C | 123.5 kPa | 42 / 63 min |
| 2,400 m | 75.6 kPa | 116.74 °C | 129.4 kPa | 53 / 80 min |

The TRL 2 version of this table gave 121.1 °C at sea level and a 300 m limit; the IAPWS-IF97 line gives 120.95 °C, so 121 °C holds only at sea level. A maker-rated vessel of about 130 kPa gauge (option A) would reach 121 °C to about 2,400 m and remains worth searching for.

## Design choices

Decided by Amish on 2026-09-25 (SCL-DDR-001): option B for altitude; the budget cuts and a $450 budget; the pitch wording; the household 12 L aluminum cooker; the level cooker at the focus with the dish tilting about it; the locally built petal dish; manual aiming by gnomon; solid, unwrapped or single-wrapped loads only; the logger pass criteria (purge plateau of 5 min or more, hold temperature and equivalent time met, and measured temperature within 2 °C of saturation throughout the hold); and backup heat on a stove.

Decided by Amish on 2026-09-25, going with the recommendation (SCL-DDR-002): R14 relaxed to retargeting every 12 min with a logger reminder (item 13); R16 relaxed to 45 kg in total with the 20 kg piece limit kept (item 14); R11 restated so the whole vessel and its fittings are a hot zone, with no physical guard, relying on turning the dish off the sun, the parking cover, goggles and a marked keep-out (item 15); four locking castors and a rule to park the dish face-up in high wind (item 16); a trimming rule with a logger trim reminder (item 17); and a 0 to 300 kPa absolute transducer (item 18).

Decided by Amish on 2026-10-02 (SCL-DEC-001):

- **Item 5: mounting the lid fittings.** Do not drill the maker's lid. Use a pressure canner sold with a factory gauge and relief valve, and carry the probe gland on an adapter plate on the vent stem that keeps a bore of 3 mm or more and leaves the overpressure plug untouched; drill a lid only with the maker's written approval. A drilled lid has no known rating; factory ports keep the maker's rating, and the relief and vent capacity calculation (SCL-CAL-001 section 8) holds for both.
- **Item 12:** the first partner to approach is a university biomedical or global health engineering group with an established rural clinic partner in a sunny region below 2,400 m, for example through an Engineering World Health university chapter. Not yet agreed.
- **Tilt lock (SCL-DDR-003, A2):** the two friction locks are kept for aiming, with a drop pin through a row of holes in the fan as a back-up stop.

## Safety

> **Safety:** SunClave concentrates sunlight to a few hundred times normal intensity at the focus, heats a pressure vessel to about 121 °C, and is described in a medical context. Each of these is a serious hazard. It is a research and educational prototype and not a medical device.

- **Concentrated sunlight.** The focal spot reaches about 270 kW/m² in its hottest part and can burn skin within about a second, ignite paper, cloth and dry grass, and cause permanent eye damage. Never look at the focus or into the dish when it faces the sun; wear the shade 5 goggles near the focus; aim only by the gnomon shadow; turn the dish at least 15° away from the sun before reaching toward the cooker; fit the parking cover whenever the dish is idle; keep the ground below clear of anything that can burn; never leave the dish facing the sun unattended or with children nearby.
- **Timber stand.** The stand is timber (decided). It is outside the converging light cone, but a mis-aimed dish or stray reflections can scorch it; keep the steel axle plates and holder between the focus and the timber, and inspect for scorching.
- **Pressure and steam.** Use only a commercially made pressure canner rated for the working pressure, keep its overpressure plug and its factory relief valve, and check that the vent is clear before every cycle. Never force the lid open; wait until the gauge reads zero and the regulator has been lifted with a tool. Steam from the regulator and relief valve can scald, so point vents away from people. Do not modify the regulator weight. Do not drill the maker's lid: use the factory gauge and relief valve of a pressure canner, and put the probe gland on an adapter plate on the vent stem with a bore of 3 mm or more, leaving the overpressure plug untouched (decided 2026-10-02, item 5). Drill a lid only with the maker's written approval.
- **Boil-dry.** A dry base under concentrated sun would pass 200 °C, where aluminum loses much of its strength. Fill 1.5 L before every cycle and trim the dish during long holds; the base-edge thermocouple alarm at 140 °C prompts the operator to turn the dish away.
- **Hot surfaces.** The lid, handles, fittings, black lower wall, base and instruments reach 121 °C or more. The whole vessel is treated as a hot zone (decided, SCL-DDR-002 item 15): mark a 2 m keep-out on the ground with the barrier tape, use heat-resistant gloves and handle the cooker only when the dish is turned at least 15° away.
- **Tipping, rolling and pinch points.** Lock all four castors and both tilt locks, and put the back-up drop pin in (decided 2026-10-02): if a friction lock slips, a 15.3 kg dish swings and its focus can sweep off the pot; the pin limits a slip to one hole. In high wind park the dish face-up. The tipping margin at low sun is thin (factor 1.38 at 10 m/s, SCL-CAL-001 section 10). Keep hands clear of the yoke plates' fans and slots when tilting; they close like scissors.
- **Lithium cells.** The power bank contains lithium cells; keep it shaded inside the logger box and do not charge it above 45 °C.
- **Medical claims.** A PASS on the logger shows the recorded conditions, not that the load is sterile. A cycle below 121 °C is recorded at its real temperature. Biological and chemical indicators remain the reference, and no load from this prototype should be used on a patient.

## Open questions after TRL 3

- Confirm a pressure canner with a factory gauge and relief valve, about 12 L, in the first target area, with its dimensions and the maker's rating (item 5 decided 2026-10-02).
- Validate the equivalent-exposure method (option B) with biological indicators; this is TRL 4 work and is on hold by Amish's instruction.
- Approach the first partner (decided 2026-10-02): a university biomedical or global health engineering group with an established rural clinic partner in a sunny region below 2,400 m, for example through an Engineering World Health university chapter, to learn real loads, altitude and records practice.

Concept media: [blueprint sheet](../media/concept-blueprint.pdf), [interactive 3D model](../media/viewer.html). General arrangement: [SCL-DWG-001](../cad/drawings/SCL-DWG-001.pdf).

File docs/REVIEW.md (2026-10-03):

# Review note: SunClave

## Session 2026-10-02: approved follow-ups carried out

Amish approved on 2026-10-02 that every follow-up action from the open-decision sign-off be carried out ("APPROVED CHANGES, COMPLETE THESE"). Nothing was built or tested; TRL 4 remains on hold. SunClave remains a research and educational prototype, not a medical device.

### Approved follow-ups carried out

Done 8 of 11:

1. Done. BOM line 6 is now a pressure canner of about 12 L sold with a factory gauge and relief valve (USD 55 to 100, indicative); lines 8 and 9 are the factory-fitted gauge and relief valve at no extra cost; line 10 is the vent-stem adapter plate with gland and probe, 6 mm bore round the probe, equal to a 5.2 mm hole (USD 30 to 45). `bom/bom.csv`, `bom/bom-notes.md`.
2. Done. `cad/src/model.py`: the canner with its factory gauge, relief valve and overpressure plug; the lid's vent-pipe hole (not drilled); the adapter plate with spigot and nut carrying the gland, probe, transducer and the maker's vent pipe and weight. New checks: adapter on the lid boss, gland and transducer on the adapter, probe clear in the bore (steam passes round it), adapter clear of the gauge and relief valve, probe tip clear of the load, factory fittings on the lid, equivalent bore 3 mm or more. The canner keeps the 288 mm outside diameter; its handles rest on the holder ring, the jacket clears the ring by 5 mm and its base is on the focal plane. STEP and STL regenerated; `python cad/src/model.py --check`: 81 of 81 checks pass (was 66), including the 15 to 90 degree tilt sweep.
3. Done. SCL-CAL-001 v0.4 section 8 restated for the factory relief valve (5.2 times the worst steam generation if its seat is 4 mm or more and it is set at 125 kPa gauge or less) and the adapter's vent path (8.0 times; the regulator's own 3 mm vent 2.7 times); the "open for Amish" rows for item 5 and SCL-DDR-003 replaced by the decisions of 2026-10-02; the canner checked against the holder and R16 (4.8 kg as bought, indicative; vessel 5.9 kg; empty total 44.8 kg).
4. Done. Build plan step 19 and the canner pictures (overview, steps 18 and 19, joint 12, sketches 117 and 118) show the canner, its factory gauge and relief valve and the adapter plate; new making sketch SCL-DWG-120 for the adapter plate.
5. Done. A row of eleven 8.5 mm holes on a 163 mm radius, 7.5 degrees apart, in each yoke plate fan; a 7.5 degree arc slot in each axle plate (now 285 mm long); a 10 x 32 mm slot through each upright; an 8 mm drop pin pushed in from outside on a lanyard to an eye screw on the upright. To make room the lock slot moved from a 150 mm to a 140 mm radius (clamp force needed 270 N per knob, was 252 N) and the logger box moved down 20 mm. New checks for the pins (through a fan hole, in the plate slot, through the upright slot, clear of the lock knobs and logger box, clear of the dish, a fan hole in the slot at every elevation from 15 to 90 degrees). The pins are pulled out to re-aim, so they are not in the tilt sweep.
6. Done. Yoke plate making sketch SCL-DWG-114 and the yoke layout picture show the pin hole row; new making sketch SCL-DWG-119 for the drop pin; upright (SCL-DWG-103) and axle plate (SCL-DWG-105) sketches show the slots.
7. Done. Joint 6 shows the drop pin; step 14 fits the pins; step 13 regenerated (longer axle plates and the slot in the uprights; the pins go in at step 14, once the lock studs are in); the "Tilt lock holds" check now includes the pins.
8. Done. BOM line 3 includes two drop pins with lanyards and eye screws (USD 30 to 36).
9. Not done: TRL 4 work (slip test plan), on hold.
10. Not done: TRL 4 work (weighing plan), on hold.
11. Not done here: the photoreal renders, card and social preview are made on Amish's Mac. Prepared for it: `cad/src/product_model.py` rebuilt on the constructable design and render scenes exported to `/home/claude/renders/sunclave` (hero, exploded, detail).

### Documents changed and new versions

- `docs/04-calcs/01-sizing.md` (SCL-CAL-001 v0.4), `docs/04-calcs/sizing.py`, `docs/04-calcs/results.csv`
- `docs/05-build-plan.md` (SCL-BLD-001 v0.3): new sections 3.20 (drop pins) and 3.21 (adapter plate); bought components, steps 14 and 17 to 19, first checks and safety stop S6 updated
- `docs/02-concept.md` (SCL-PRC-001 v0.7), `docs/03-requirements.md` (SCL-REQ-001 v0.7), `docs/06-design-decisions.md` (SCL-DEC-001 v0.3), `docs/decisions/0003-design-for-construction.md` (SCL-DDR-003 v0.3)
- `cad/src/model.py`, `cad/step/*.step`, `cad/stl/*.stl`; `cad/src/sheets.py` and SCL-DWG-001 Rev P4
- `cad/src/build_plan_media.py`: making sketches SCL-DWG-103, 105, 114, 117 and 118 regenerated, SCL-DWG-119 and 120 new; overview, yoke layout, all joint and step pictures regenerated
- `cad/src/concept_media.py` and the concept media in `media/`
- `cad/src/product_model.py` (appearance model)
- `bom/bom.csv`, `bom/bom-notes.md`, `README.md` (not controlled documents)
- `docs/pdf/`: every controlled document re-rendered

### Key results (SCL-CAL-001 v0.4)

- No requirement changed status: 13 met, 2 at risk (R4, R15), 1 not verifiable at TRL 3 (R1); R17 reported against the target.
- R16 mass: 44.8 kg against 45 kg (was 44.4 kg), so the margin is now 0.2 kg. Met, but thinner than the 0.6 kg Amish accepted; a canner heavier than about 5.0 kg would take it over.
- R4: 81 min central, 72 to 111 min (was 80, 71 to 109): the canner's heavier body takes longer to heat.
- R15: tipping factor 1.40 (was 1.38).
- R8: met on capacity; the factory relief valve's seat and set pressure are purchase criteria, not known values.
- Value-engineering target: USD 450. Estimated cost of the constructable design: USD 528 (USD 78 over the target; was USD 497).

### Proposed, awaiting Amish

1. **R16 margin of 0.2 kg.** Options: (a) keep the accepted plan and weigh at TRL 4; (b) adopt the 5 mm yoke plates and lighter holder arms now. Recommendation: (a), and choose a canner of 5.0 kg or less with its fittings.
2. **Appearance model.** `cad/src/product_model.py` now takes every part from the constructable model; the appearance details (petal rivets, hub cap, canner rim, handle grips, jacket seams, gauge face, logger display and labels) add no BOM lines. The 2026-09-26 differences (taller logger enclosure, transducer on the tee, handles, petal seams) no longer apply. Recommendation: accept.

### Cross-repo actions

None.

### Safety

The canner's lid is never drilled; the factory relief valve and overpressure plug are untouched; the adapter plate's joint has no rating until the hydrostatic check of safety stop S6 (TRL 4 work). The drop pins are pinch points and must be pulled out before the knobs are loosened to re-aim; both are in the build plan.

### Recommended next step

Render session on Amish's Mac from the exported scenes, then `python .kit/cards.py .`. TRL 4 remains on hold.

## Session 2026-10-01: kit 1.7.0, constructable design and prototype build plan

Following Amish's 2026-09-30 approval of the build plan format ("this is the correct build plan ... Extend this across all the other repos"), his instruction to make each design physically buildable, and his 2026-10-01 note that budgets are value-engineering targets.

### What was done

- Kit 1.7.0 installed (`.kit/`, `.claude/commands/`); `CLAUDE.md` replaced with `.kit/CLAUDE.md`.
- Constructability review with build123d of the TRL 3 model: nine problems found (overlaps, floating parts, parts with no fixing, no feasible assembly order), listed in `docs/decisions/0003-design-for-construction.md` (SCL-DDR-003 v0.1, Draft: made under Amish's 2026-09-30 instruction to make the design physically buildable; open for his review).
- `cad/src/model.py` rewritten as a part-by-part constructable model with `python cad/src/model.py --check`: 66 checks (contacts, clearances and a 15 to 90 degree tilt sweep), all passing. STEP and STL regenerated in `cad/step/` and `cad/stl/`.
- `bom/bom.csv` lines 1 to 5, 14, 16 and 17 respecified and repriced; `bom/bom-notes.md` updated.
- `docs/04-calcs/sizing.py` now takes the structure's masses and the tilting group's centre of mass from the model, adds the holder ring and handles to the ray trace, computes the lock clamp force, and reports cost against the value-engineering target. SCL-CAL-001 v0.3, SCL-REQ-001 v0.5 and SCL-PRC-001 v0.5 updated.
- `cad/src/sheets.py`: SCL-DWG-001 Rev P3.
- `cad/src/build_plan_media.py` (new): overview, 18 making sketches (SCL-DWG-101 to 118), petal flat pattern and yoke plate layout, 14 joint close-ups and 19 assembly step pictures in `docs/05-build-plan/` and `cad/drawings/`.
- `docs/05-build-plan.md` (SCL-BLD-001 v0.1) and `docs/06-design-decisions.md` (SCL-DEC-001 v0.1) written; `project.yaml` has `design_state: constructable` and both in `trl_evidence`; README links line and "Building the prototype" section added; concept media regenerated.

### Design changes made for construction

1. Pivots: steel axle plates on the uprights, fixed 20 mm axles with collars, PTFE thrust washers, and 6 mm yoke plates that turn on the axles (replacing the bearing blocks, stub axles and collars, which overlapped).
2. Tilt lock: a slotted fan on each yoke plate clamped by a star knob on a fixed M10 stud, both sides (replacing the quadrant plate and lever, which passed through the bearing block).
3. Yoke to dish: a rectangular tube stand-off each side, clamped to the rim band by two M8 countersunk screws (the tube arms stopped short of the rim, and one bolt per side would have let the dish swing).
4. Pot holder: a flat steel ring the cooker handles rest on, on tube arms carried on the upright tops and angle brackets (the ring ran through the jacket and sat 28 mm below the handles).
5. Stand: side rails on edge across the cross rails, uprights turned 90 degrees on angle brackets, braces lapped and bolted, real 102 mm castors bolted inboard of the side rails, cross rails 40 mm longer for bolt end distance.
6. Dish frame: petals with folded flanges riveted through the ribs and tabs riveted to the rim; rib clips at the hub and rim; hub plate 200 x 4 mm; rim band 25 x 4 mm; ribs offset 15 degrees from the stand-offs.
7. Gnomon on a bracket outside the rim band (it sat on the reflector face with no fixing).
8. Logger box sized to hold the power bank, below the lock stud; transducer on the tee; plug-in sensor leads; thermocouple band clamp.
9. Assembly order made possible: a 2 mm gap at each pivot, one axle plate fitted after the dish is in.

### Key results (SCL-CAL-001 v0.3)

- Absorbed power 663 W in the design case (was 669 W); cycle 80 min central, 71 to 109 min (R4 at risk).
- Mass 44.4 kg against 45 kg (R16 met, 0.6 kg margin, was 41.0 kg); largest piece 15.4 kg; the stand now comes apart.
- Tipping factor 1.38 at 15 degrees (was 1.30; R15 at risk). Lock torque up to 45 N·m, 252 N clamp per knob needed.
- Value-engineering target: USD 450. Estimated cost of the constructable design: USD 497 (USD 47 over the target; was USD 440).
- Requirement status: 13 met, 2 at risk (R4, R15), 1 not verifiable at TRL 3 (R1), 0 not met; R17 reported against the value-engineering target.

### Decisions proposed and awaiting Amish

All are in the design decisions register (`docs/06-design-decisions.md`): accept SCL-DDR-003 (recommended; it also settles the four appearance-model differences of 2026-09-26); the 0.6 kg mass margin (A1); friction locks or a back-up pin (A2); and, unchanged, the lid-fitting method (item 5) and the first partner and site (item 12).

### Safety

No change to the pressure vessel, regulator, relief valve, lid fittings or hot-zone rules. The new pivots and locks are pinch points (the fans close like scissors as the dish tilts) and the locks are friction clamps; they are covered by safety stop S2, and the choice of a back-up pin is open as A2. The build plan stops before the cooker is pressurised (S6). SunClave remains a research and educational prototype, not a medical device.

### Stale until refreshed on Amish's Mac

The design changed visibly, so `media/render-hero.png`, `media/render-exploded.png`, `media/render-detail.png`, `media/card.png`, `media/social-preview.png` and the appearance model `cad/src/product_model.py` still show the concept's tube yoke, quadrant, bearing blocks, holder and stand. They were not regenerated here.

### Recommended next step

Amish reviews SCL-DDR-003 and the register. TRL 4 remains on hold.

## Session 2026-09-26: product appearance model and photoreal renders

Amish chose this repo for the first batch of product renders on 2026-09-26.

### What was added

`cad/src/product_model.py` exposes `product_parts()` (94 parts: 61 shell, 28 internal, 4 accessory, 1 context), `TITLE` and `RENDER_VIEWS` (hero, exploded, and a detail view of the cooker at the focus without the dish, stand or ground). It imports PARAMS, derived(), dish_local(), to_world(), point_world() and tilt_of() from `cad/src/model.py`; the dish diameter and focal length, the tilt pose, the focal height, the stand, castor and bearing positions, the cooker, lid, jacket, basket and lid fitting positions and the logger position are as model.py. It adds:

- Dish: the reflector split into 12 petals with visible seams over the ribs, paired rivet rows along each seam, a hub cap with bolts; painted steel ribs, rim and hub; the gnomon with a white target plate, teal target rings and a stainless pin. In the exploded view the petals move radially outward so the ribs show between them.
- Tilt yoke with bearing collars and grease bosses, the lock lever and a knurled black knob; the slotted quadrant plate with white tick marks.
- Timber stand with rounded arrises, carriage bolts, painted steel bearing blocks with bolt heads and axle caps, and four castors with rubber wheels, zinc forks and teal brake pedals.
- Level pot holder ring and arms.
- Cooker: aluminum body with a rolled rim, the blackened base and lower wall band, handle brackets with black phenolic grips; the aluminized jacket with stitched seams, two straps and buckles; the lid with a gasket line, boss, phenolic handle, vent pipe and weighted regulator.
- Lid fittings: the pressure gauge with stainless case, dial, scale marks, red zone, needle and clear glass; the brass relief valve with its test ring; the brass lid gland, Pt100 sheath and tee; the pressure transducer with its connector.
- Inside the cooker: water charge, perforated stainless basket on its trivet, and a wrapped instrument pack with indicator tape in place of model.py's instrument load block (same size and position).
- Logger: IP65 enclosure with side ribs, lid and screws, OLED display with a lit readout, two teal buttons, a lit green PASS light and an unlit red FAIL light, buzzer grille, rating label, teal name band, cable glands and mounting straps round the upright; inside, the logger board and modules, microSD holder and the USB power bank (exploded view only); the cable from the logger to the lid.
- Context (not in the BOM): a compact paved ground patch under the stand. No mannequin, because SunClave is used standing still at a fixed spot.

`README.md` now shows `media/render-hero.png` and links `media/render-exploded.png`; the orchestrator produces both files.

### Differences from model.py (Proposed, awaiting Amish)

1. **Logger enclosure height.** BOM line 15 says the power bank is kept in the logger box, but model.py draws a 60 x 150 x 110 mm logger box with the 50 x 140 x 60 mm power bank hanging below it, outside. The appearance model extends the enclosure downward to 60 x 150 x 183 mm (bottom at 862 mm, top unchanged at 1,045 mm) so the power bank sits inside at its model.py position. Proposed, awaiting Amish. Recommendation: adopt the taller single enclosure in model.py and BOM line 14 at the next revision; option: a separate small box for the power bank.
2. **Pressure transducer on the tee.** BOM line 14 includes a stainless pressure transducer on the lid tee (BOM line 10), but model.py ends the logger cable at the tee without a transducer body. The appearance model shows a 22 mm diameter transducer standing on the tee end with its connector, and the cable ends there. Proposed, awaiting Amish. Recommendation: add the transducer envelope to model.py at the next revision.
3. **Cooker handles.** model.py's handle bar is one massing block that passes through the cooker interior. The appearance model shows two handles outboard of the wall with the same overall span (458 mm) and height. Proposed, awaiting Amish. Recommendation: accept as appearance detail.
4. **Petal seams and hub.** model.py's reflector is one revolved sheet to the axis. The appearance model cuts 2.4 mm seams at the rib angles and a central opening inside the 75 mm hub radius, covered by a hub cap. Proposed, awaiting Amish. Recommendation: accept; it matches the 12-petal build in BOM line 1.
5. **Not shown.** The base-edge K-type thermocouple lead (BOM line 14), eye protection, parking cover, keep-out marking and validation consumables (BOM lines 18 to 21) are not modelled, as in model.py. Screws, straps, glands and bolts are appearance detail under BOM line 17; no new BOM lines are implied.

### Status

This is an appearance model only: no tolerances, no fabrication detail, nothing past TRL 3. `trl: 3` and `trl_target: 3` are unchanged, and TRL 4 remains on hold. model.py, the BOM and the other documents were not edited.

## Session 2026-09-26: sources strengthened

Amish, 2026-09-26: "Fix the weaker sources." All README source links in the Concept rationale, Burning platform, Where it could be used and What sparked the idea sections were fetched and checked against the claims they support.

| Where | Old source | New source |
| --- | --- | --- |
| By country or region: Andean Peru and Bolivia | None (row uncited) | Row rewritten as Peru and Bolivia (Andes) and cited to the [WHO fact sheet on electricity in health-care facilities](https://www.who.int/news-room/fact-sheets/detail/electricity-in-health-care-facilities): in Latin America and the Caribbean about 8 % of facilities have no electricity and about 72 % have a reliable supply. No altitude figure is claimed. |
| By country or region: Sahel (Niger, Mali, Chad) | Global Solar Atlas (could not be fetched for verification); grid claim uncited | Narrowed to Niger and cited to the [African Development Bank Desert to Power roadmap for Niger (2020)](https://www.afdb.org/sites/default/files/2024/08/23/desert-to-power_dtp_roadmap_for_niger_en_oct2020.pdf): daily irradiation about 7 kWh/m², electricity access about 13 % nationally and about 1 % in rural areas in 2018. |
| By country or region: Puerto Rico | US Army Corps of Engineers fact sheet (returned HTTP 403, could not be verified) | [GAO-19-296](https://www.gao.gov/products/gao-19-296): about 11 months to restore power to all customers after Hurricanes Irma and Maria in 2017. |
| By country or region: Kenya | Uncited claim that many facilities sit at 1,000 to 2,000 m | Removed; the row keeps the cited WHO figure and the cooker physics from the calculation note. |

Links kept after verification: WHO fact sheet on electricity in health-care facilities, WHO questions and answers on surgical site infections, Bureau International des Expositions on Mouchot at Expo 1878, Smithsonian National Museum of American History (Papin 1679, Chamberland 1879). The inspiration already rests on primary and museum sources, so it and INSPIRATIONS.md are unchanged. docs/01-problem.md cites the Global Solar Atlas (World Bank and ESMAP data) for a different claim (clear-sky DNI) and is unchanged. No controlled document changed, so no version was bumped.

## Session 2026-09-25: recommendations accepted

Amish wrote, in chat on 2026-09-25: "i accept all your recommendations, go with them across all repos." Every open item with a recommendation (items 13 to 18) is now **Decided by Amish, 2026-09-25: go with recommendation**, recorded in `docs/decisions/0002-recommendations-accepted.md` (SCL-DDR-002 v0.1). Items 1 to 4 and 6 to 11 were already decided (SCL-DDR-001).

### Decisions applied and what changed

| # | Decision | Before | After |
| --- | --- | --- | --- |
| 13 | R14 relaxed to retargeting every 12 min, with a logger reminder | Target 15 min; 13 min achieved; not met | Target 12 min; met. Mean absorbed power 630 W to 638 W; central cycle 79.9 min to 79.0 min; unfavourable 109.2 min to 106.6 min |
| 14 | R16 total relaxed to 45 kg, 20 kg piece limit kept | 41.0 kg against 40 kg; not met | 41.0 kg against 45 kg; met |
| 15 | R11 restated: whole vessel a marked hot zone, no physical guard | Guard undefined; not met | Met by design review; BOM item 21 keep-out marking added ($6) |
| 16 | Four locking castors; park face-up in high wind | Two locking; grip 109 N against 153 N of wind | Four locking; grip 218 N; castors $40 to $44; model adds brake pedals; SCL-DWG-001 Rev P1 to P2. Tipping factor still 1.30, R15 still at risk |
| 17 | Trimming rule with a logger trim reminder for holds over 40 min | 0.14 kg of water left at 1,800 m in strong sun; at risk | 1.31 kg at 1,800 m and 1.28 kg at 2,400 m with trimming; met (R10 restated) |
| 18 | 0 to 300 kPa absolute transducer, overpressure rating 600 kPa or more | Check uncertainty 0.89 K, pressure 5 kPa; at risk | 0.64 K (32 % of the 2 K threshold), pressure 3 kPa; met, narrowly |

Budget: unchanged at $450 in `project.yaml`. Parts rose from $430 to $440, a margin of $10.

Files changed: `docs/03-requirements.md` (SCL-REQ-001 v0.4: R10, R11, R14 and R16 restated or relaxed; status column), `docs/02-concept.md` (SCL-PRC-001 v0.4), `docs/04-calcs/sizing.py`, `results.csv` and `01-sizing.md` (SCL-CAL-001 v0.2), `docs/decisions/0001-trl2-review-decisions.md` (SCL-DDR-001 v0.2, items 13 to 18 marked decided), `bom/bom.csv` and `bom-notes.md`, `cad/src/model.py` (four castor brake pedals; STEP and STL re-exported), `cad/src/sheets.py` (SCL-DWG-001 Rev P2, notes), `cad/src/concept_media.py` (cost figure; all media regenerated and inspected), `project.yaml` (DDR-002 added to the evidence list) and `README.md`.

README: added "Concept rationale", "Burning platform" (WHO electricity and surgical site infection figures), "Where it could be used" and "What sparked the idea". The inspiration is Augustin Mouchot's parabolic solar collector heating a blackened boiler at the 1878 Paris Exposition, together with Chamberland's 1879 autoclave descended from Papin's pressure cooker. `docs/01-problem.md` did not attribute the idea to any session and was not changed. All generated files were re-rendered with the designmolecule.com footer.

### Requirement status (SCL-CAL-001 v0.2)

14 met, 2 at risk, 1 not verifiable at TRL 3, 0 not met.

- Not met: none. R11, R14 and R16 are met because their targets were restated or relaxed by decision, not because the design improved.
- At risk: R4 cycle time (79 min central, 107 min unfavourable, against 90 min); R15 stability (tipping factor 1.30 at 15° sun in a 10 m/s wind).
- Not verifiable at TRL 3: R1, because the equivalent-exposure method needs biological indicators.
- Met: R2, R3, R5, R6, R7, R8, R9, R10, R11, R12, R13, R14, R16, R17.

### Still awaiting Amish

- **Item 5: mounting the lid fittings** (drilled lid, factory ports or adapter plate). No recommendation; a pressure-safety trade-off. Must be decided before anything is built.
- **Item 12: first partner and site.** No recommendation; chosen per area later.

### Cross-repo actions

None. No SunClave decision needs another repo to change.

### Safety

The restated R11 relies on procedure (turning the dish 15° off the sun, the parking cover, goggles and a marked keep-out) rather than a physical guard, and the restated R10 relies on the operator following the trim reminder. Both keep the 140 °C base alarm and the safety sections unchanged. SunClave remains a research and educational prototype, not a medical device.

### TRL

`trl: 3` and `trl_target: 3`. TRL 4 remains on hold by Amish's instruction. The retarget and trim reminders are recorded as firmware rules only; no firmware, purchasing, build or test work was done.

## Session 2026-09-25: TRL 3

TRL 4 is on hold by Amish's instruction ("Make sure we don't proceed to TRL 4 on any of them"). This session took SunClave from TRL 2 to TRL 3 and stopped there.

### What was done

- `docs/decisions/0001-trl2-review-decisions.md` (SCL-DDR-001 v0.1): records items 1 to 4 and 6 to 11 of the TRL 2 review as "Decided by Amish, 2026-09-25: go with recommendation", the cross-cutting approvals (SwapCell does not apply), and the open items 5, 12 and 13 to 18.
- `docs/04-calcs/01-sizing.md` (SCL-CAL-001 v0.1) with `docs/04-calcs/sizing.py` and `docs/04-calcs/results.csv`: IAPWS-IF97 steam and altitude, a Monte Carlo ray trace of the dish onto the level cooker, heat loss, cycle and clear-day simulation, measurement uncertainty, relief and vent capacity for both lid options, boil-dry, masses, wind and castor grip, logger power, cost, and a results table for R1 to R17. The script reads `cad/src/model.py` and `bom/bom.csv`.
- `cad/src/model.py`: parametric build123d model (paraboloid reflector, ribs, rim, yoke, timber stand, fixed pot holder, 12 L cooker with lid fittings, jacket, water, basket, logger and power bank). Exports `cad/step/sunclave-{assembly,dish,stand,vessel}.step` and matching STL files in `cad/stl/`.
- `cad/src/sheets.py` and `cad/drawings/SCL-DWG-001.svg`, `.pdf`, `.png`: general arrangement, Rev P1, marked "CONCEPT, NOT FOR FABRICATION" and "PRELIMINARY, NOT FOR FABRICATION". The concept sheet keeps SCL-DWG-010, so SCL-DWG-001 was the next free number.
- `bom/bom.csv` and `bom/bom-notes.md`: 20 lines, every line priced with a supplier type; parts total $430 against $450.
- `cad/src/concept_media.py` now builds the media from the model: `media/hero.png`, `exploded.png`, `cutaway.png`, `flow.png` (SCL-CAL-001 numbers), `concept-blueprint.png`, `.pdf`, `.svg`, `model.glb` and `viewer.html`. Each image was inspected; exploded offsets were adjusted so the stand and dish callouts no longer overlap. No `media/_views*` folders remain.
- SCL-PRB-001, SCL-PRC-001 and SCL-REQ-001 moved to v0.3 with the decisions and the TRL 3 numbers. `project.yaml`: `trl: 3`, `trl_target: 3`, evidence list, new pitch, `budget_usd: 450`. `README.md`: new pitch, TRL 3 badge and summary.

### Requirements (SCL-CAL-001 Table 10)

9 met, 4 at risk, 1 not verifiable at TRL 3, 3 not met.

- **Not met: R11 burn and glare.** No focal-zone guard is defined, and the black base and 80 mm wall band (above 60 °C) are within reach. Goggles and a parking cover were added to the BOM.
- **Not met: R14 tracking.** Absorbed power stays within 10 % of on-target for about 13 min of sun motion (3.2° of pointing error), not 15 min.
- **Not met: R16 mass.** About 41.0 kg empty against 40 kg, mostly because the decided timber stand weighs about 19.4 kg. Every handling piece is within 20 kg.
- At risk: R4 cycle time (80 min central, 109 min unfavourable, against 90 min); R10 boil-dry (option B holds at 1,800 m in strong sun leave 0.14 L without trimming); R12 air-removal check (0.89 °C uncertainty against 2 °C); R15 stability (tipping factor 1.30 at 15° sun, and the stand rolls on two locked castors).
- Not verifiable at TRL 3: R1, because the equivalent-exposure method of option B needs biological indicators.
- Met: R2, R3, R5 (4 cycles), R6, R7 (0.44 °C with a 0.05 % reference), R8 (relief 5.1 times the worst steam generation), R9, R13 (8.7 days), R17 ($430).

Corrections to TRL 2 numbers (SCL-CAL-001 section 14): the regulator gives 120.95 °C at sea level, so 121 °C holds only at sea level, not below 300 m; absorbed power is 669 W, not 710 W; heat loss at 121 °C is 395 W, not 200 W; peak flux is about 270 kW/m², not 30 to 50; the 270 x 180 mm basket did not fit a 12 L cooker and is now 250 x 150 mm.

### Decisions recorded (SCL-DDR-001)

Decided by Amish, 2026-09-25, going with the recommendation: altitude option B; budget option (b) then (a), so `budget_usd` is now $450 after the cuts saved about $29; the pitch wording; the household 12 L aluminum cooker; the level cooker at the focus (the holder is fixed to the stand, because a swinging holder would be top-heavy); the petal dish; manual gnomon aiming; the load limits; the logger pass criteria; backup heat on a stove. The problem line had no recommended rewording and is unchanged.

### Still awaiting Amish

- **Item 5: drilling the cooker lid** versus a factory-ported cooker or an adapter plate. No recommendation; it is a safety trade-off. The model shows the fittings without choosing, and SCL-CAL-001 section 8 lists both options side by side.
- **Item 12:** first partner and site (per area later).
- **New items 13 to 18,** each with a recommendation: R14 (relax to 12 min), R16 (relax to 45 kg total), R11 (treat the whole vessel as a hot zone, no physical guard), R15 (four locking castors, about $4), R10 (trimming rule and logger water warning), R12 (0 to 300 kPa transducer). **Decided by Amish, 2026-09-25: go with recommendation** (SCL-DDR-002; see the session below).

### Safety concerns

- The focal spot is far hotter than the TRL 2 documents said: about 270 kW/m² in its hottest 20 mm. Goggles, gnomon aiming, the parking cover and turning the dish at least 15° away before reaching in are essential. R11 is not met.
- The lid-fitting method (item 5) must be decided before anything is built. Relief and vent capacity are ample for both options, but no calculation can show whether a drilled lid keeps the maker's rating.
- Option B at altitude lengthens holds; in strong sun the cooker can boil nearly dry at 1,800 m and fully dry at 2,400 m unless the dish is trimmed. A dry base would pass 200 °C.
- The base thermocouple must sit at the base edge, out of the focal spot, or the boil-dry alarm will misread. Normal boiling leaves only 6.5 K of margin to the 140 °C alarm.
- The quadrant lock carries up to about 38 N·m of gravity torque plus wind; the stand can roll in a 10 m/s wind on two locked castors.
- The timber stand can scorch from stray reflections; the power bank is a lithium pack and must stay shaded.
- Medical claims: the documents still state that SunClave is a research and educational prototype, not a medical device, and that a PASS does not prove sterility.

### Problems and notes

- The kit's exploded-view callouts still cover the smallest parts (gauge 8, relief valve 9, gland 10 and power bank 15) at this scale. A kit change (offset labels with leader lines) would fix it; not made here.
- The kit's cutaway cutter is centered on Z = 0, so `concept_media.py` still lowers the vessel before cutting (as at TRL 2).
- The reflector is modelled 3 mm thick for visibility; mass uses 0.5 mm.
- No citations were flagged as unchecked in the TRL 2 review; none were re-verified. The new CAL cites Watmuff, Charters and Proctor (1977) for wind convection and uses IAPWS-IF97, checked in the script against steam-table values.
- No TRL 4 material exists in this repo (`build-log/` holds only its README; `electronics/` and `firmware/` are empty).
- Suggestions, not changes: an insulated lid cover could recover up to about 80 W of the 101 W lid loss and shorten heat-up; a kit fix for callouts.

### Recommended next step

Decide item 5 (lid fittings) and items 13 to 18, then update SCL-REQ-001 and the BOM on paper. TRL 4 is on hold by Amish's instruction and no TRL 4 work should start. For the record only, TRL 4 would need: a built prototype with the lid-fitting decision implemented; a lab test report (TST, `environment: lab`) covering a hydrostatic check of the vessel as fitted, the relief valve lift, heat-up and hold timing, logger calibration against a reference thermometer and barometer, the air-removal check with a deliberate leak, and biological and chemical indicators for the option B equivalence; and dated build log entries.

## Session 2026-09-25: /populate to a strong TRL 2 (overnight batch)

### What was done

- `docs/01-problem.md` (SCL-PRB-001 v0.2): problem with cited sources (WHO electricity data, CDC and IARC cycle times, WHO reprocessing manual), users, operating environment, constraints, out of scope, cited prior work (Kaseman et al. solar autoclave, Rice nanoparticle autoclave, SK14 dish, pressure-cooker sterilization, EN 13060 type N), open questions, and a co-design checklist.
- `docs/03-requirements.md` (SCL-REQ-001 v0.2): 17 measurable requirements (R1 to R17) with a defined design case, verification route and concept status for each.
- `docs/02-concept.md` (SCL-PRC-001 v0.2): how it works, 16 numbered components, solar input, heat-up and water budget, altitude table, logger accuracy, aiming, wind, mass and cost, design choices, safety, open questions.
- `cad/src/concept_media.py`: massing model of the petal dish, ribs, tilt yoke, castored stand, level pot holder, cooker with lid fittings, jacket, water, basket, logger, panel and gnomon, each with a BOM number; 1.75 m scale figure. The cutaway is rendered with the kit's `cutaway_parts` and `_render` on the pressure vessel only (see notes).
- `media/`: `hero.png`, `concept-blueprint.png`, `.pdf` and `.svg`, `exploded.png` with BOM callouts, `cutaway.png` of the vessel, `flow.png` (power during heat-up, estimates), `model.glb` and `viewer.html`.
- `bom/bom.csv`: 18 lines numbered to match the exploded view, indicative USD prices; `bom/bom-notes.md` updated.
- `README.md`: hero image and links line before "## Problem"; problem, concept and key components brought in line with the precis; safety note extended to concentrated sunlight.
- `docs/pdf/`: branded PDFs of the three controlled documents.
- `project.yaml` unchanged.

### Key results (estimates, to be checked at TRL 3)

| Quantity | Estimate | Requirement |
| --- | --- | --- |
| Power absorbed by the cooker at 700 W/m² DNI | about 710 W (1.4 m dish, 1.54 m²) | |
| Cold start to 121 °C | about 35 min; 35 to 60 min with aiming losses | R4 met on estimate, at risk (precedent 93 to 183 min) |
| Cycle, cold start to end of hold | about 55 to 90 min | R4 (90 min) |
| Cycles per clear day | about 3; none when overcast | R5 met on estimate |
| Water left after a 30 min hold | about 1.0 L of 1.5 L | R10 met |
| Steam temperature at 103 kPa gauge | 121.1 °C at 0 m; about 117.8 °C at 1,800 m | **R1 not met above about 300 m** |
| Temperature accuracy | about 0.5 °C (Pt100 class A) | R7 met on datasheets |
| Logger autonomy without sun | about 5 days | R13 met |
| Wind at 10 m/s | about 110 N·m overturning versus about 180 N·m restoring | R15 met, thin margin |
| Mass, empty | about 32 kg | R16 met |
| Parts cost | about $437 (validation consumables about $45 extra) | **R17 not met, about 9 % over** |

Requirements not met or at risk:

- **R1 (sterilizing temperature) not met above about 300 m** with a 103 kPa cooker. Many target sites are at 1,000 to 2,000 m.
- **R17 (cost) not met:** about $437 against $400.
- **R4 (cycle time) at risk:** the estimate is well below the only measured precedent.
- **R11 (burn and glare protection) partly met:** a focal-zone guard is not yet defined.
- **R12 (air-removal check)** is feasible, but the 5 kPa pressure accuracy leaves little margin on the 2 °C threshold.

### Proposed, awaiting Amish

Status update: items 1 to 4 and 6 to 11 are **Decided by Amish, 2026-09-25: go with recommendation** (SCL-DDR-001). Items 5 and 12 had no recommendation and remain proposed, awaiting Amish.

1. **Altitude strategy.** Option A: a vessel rated by its maker for about 130 kPa gauge. Option B: keep the 103 kPa cooker and extend the hold by an equivalent-exposure calculation (unvalidated; needs biological indicators). Option C: sites below about 300 m only. Recommendation: B for the research prototype, recorded plainly as a lower-temperature cycle, with a search for A.
2. **Budget.** Option (a): raise `budget_usd` to $450. Option (b): cut about $40 (timber stand instead of steel, OLED instead of e-paper, a USB power bank instead of the logger panel). Option (c): accept the overrun for the prototype and state it. Recommendation: (b), then (a) if the savings fall short. `project.yaml` is unchanged.
3. **Pitch wording.** The pitch says "validated temperature and time logger". The logger can be calibrated and can record evidence, but neither it nor the system is validated in the regulatory sense, and a PASS does not prove sterility. Proposed wording: "with a calibrated temperature, pressure and time logger that records every cycle". Not changed in `project.yaml` or the README tagline, because it changes the pitch.
4. **Pressure vessel:** household 12 L aluminum cooker (about $55) rather than a purpose-made sterilizer such as the All-American 1915X (about $430 alone).
5. **Drilling the cooker lid** for the probe gland, transducer, gauge and relief valve, versus a cooker with factory ports or an adapter plate on the regulator stem. Safety trade-off.
6. Level cooker hung at the focus with the dish tilting about it.
7. Locally built 1.4 m petal dish rather than a Scheffler reflector or a bought SK14 kit.
8. Manual aiming with a shadow gnomon; no tracker.
9. Load limits: solid instruments only, unwrapped or single-wrapped.
10. Logger pass criteria: purge plateau of 5 min or more, hold temperature and time met, and measured temperature within 2 °C of saturation.
11. Backup heat on cloudy days from a wood, charcoal or LPG stove, logged the same way.
12. First partner and site for co-design.

### Safety concerns

- Concentrated sunlight (about 30 to 50 suns at the focus): eye damage, skin burns and fire. Aiming by shadow, goggles, a parking cover and a focal-zone guard are needed.
- Pressure vessel: only a maker-rated cooker, overpressure plug kept, an independent relief valve, no change to the regulator weight, and never forcing the lid. Drilling the lid needs a careful decision (item 5).
- Boil-dry of an aluminum base under concentrated sun; mitigated by the water budget and the base thermocouple alarm.
- Scalds from steam venting, hot instruments and lid; tipping in wind; pinch points at the pivots.
- Small lithium cell in a sunny location.
- Medical claims: the documents state that SunClave is a research and educational prototype, not a medical device, and that a logger PASS does not prove sterility. These statements must stay.

### Problems and notes

- The kit's cutaway cutter is centered on Z = 0, so it misses parts about 1 m up when the large stand and dish are excluded. `concept_media.py` lowers the vessel parts before cutting and calls the kit's `cutaway_parts` and `_render` directly. Suggest fixing `cutaway_parts` in the kit to center the cutter on the parts' bounding box (a kit change, not made here).
- In the exploded view the smallest parts (gauge, relief valve, gnomon) are partly covered by their callout circles at this scale.
- The dish is modeled as a spherical cap as a stand-in for the paraboloid (massing only).
- The legacy `cad/src/model.py` placeholder is untouched (TRL 3 work).
- SwapCell is not relevant to this design and is not proposed.

### Recommended next step

Review this note and the media, then decide items 1 to 3 (altitude, budget, pitch wording) and item 5 (drilling the lid). If approved, run `/advance-trl3` to check the optics, heat-up and water budget, altitude method and wind stability by calculation, and produce the parametric model and drawing sheet.

## Session 2026-09-27: kit 1.5.0 and image quality

- Kit 1.5.0 synced: STANDARDS v1.5 (sections 12 to 15: product renders, storefront images and image quality, public release, authorship and signing), `.kit/cards.py`, `.kit/image_qc.py`, `.kit/release_gate.py`, issue templates, and the `/render-product` and `/release` commands. `CLAUDE.md` now matches `.kit/CLAUDE.md`.
- Every `media/render-*.png` recaptioned from its original render with the new layout: the title, concept label and repository sit in a band above the render and the view note in a band below it, each line wrapped to the image width, so no text overlaps other text or the render or runs off the image. `media/card.png` and `media/social-preview.png` regenerated with the same rules.
- `python .kit/image_qc.py` and `python .kit/release_gate.py` pass. trl stays 3.

## Session 2026-10-02: open decisions decided

On 2026-10-02 Amish approved every recommendation written for the open decisions: "i approve your recommendations for all 555 open decisions." Nothing was built or tested; TRL 4 remains on hold.

### Decisions recorded

5 decisions moved from "Open decisions" to "Decisions made" in the design decisions register, dated 2026-10-02. Lid fittings decided (no drilling; a pressure canner with a factory gauge and relief valve, the probe gland on a vent-stem adapter plate); design for construction (SCL-DDR-003) accepted with A1 and with A2 changed to add a back-up drop pin; a university biomedical or global health engineering group named as the first partner to approach. Nothing is to be pressurised until the follow-ups for decision 1 are carried into the design.

### Documents changed

- `docs/01-problem.md` (SCL-PRB-001 v0.4)
- `docs/02-concept.md` (SCL-PRC-001 v0.6)
- `docs/03-requirements.md` (SCL-REQ-001 v0.6)
- `docs/05-build-plan.md` (SCL-BLD-001 v0.2)
- `docs/06-design-decisions.md` (SCL-DEC-001 v0.2)
- `docs/decisions/0001-trl2-review-decisions.md` (SCL-DDR-001 v0.3)
- `docs/decisions/0002-recommendations-accepted.md` (SCL-DDR-002 v0.2)
- `docs/decisions/0003-design-for-construction.md` (SCL-DDR-003 v0.2)
- `README.md` (not a controlled document)
- `bom/bom-notes.md` (not a controlled document)
- `docs/pdf/`: every controlled document re-rendered.

### Follow-up actions to carry approved decisions into the design

The model, drawings, build plan pictures, BOM quantities and prices, and calculations were not changed in this session. These actions carry the approved decisions into them:

1. Decision 1 (bom): Respecify BOM line 6 as a pressure canner of about 12 L sold with a factory gauge and relief valve; lines 8 and 9 become the factory-fitted parts or are removed; line 10 gains the vent-stem adapter plate with a bore of 3 mm or more; reprice.
2. Decision 1 (model): Model the pressure canner with its factory gauge and relief valve and the vent-stem adapter plate carrying the probe gland; check the canner fits the holder ring and the focus.
3. Decision 1 (calcs): SCL-CAL-001 section 8: restate the relief and vent capacity for the factory relief valve and the 3 mm vent-stem bore, and replace the "open for Amish" wording on item 5 and SCL-DDR-003 with the decisions of 2026-10-02; check the canner's volume, mass and dimensions against R16 and the holder.
4. Decision 1 (pictures): Build plan step 19 and the cooker pictures: show the canner, its factory fittings and the adapter plate.
5. Decision 4 (model): Add a row of pin holes in each yoke plate fan and a drop pin with a lanyard on the stand; re-run the constructability checks.
6. Decision 4 (drawings): Yoke plate making sketch: add the pin hole row; making sketch for the drop pin.
7. Decision 4 (pictures): Build plan: joint 6 (tilt lock) and steps 13 and 14 pictures to show the drop pin; add the pin to the "Tilt lock holds" check.
8. Decision 4 (bom): BOM line 3: add the drop pins and lanyards and price them.
9. Decision 4 (docs): TRL 4 test plan: slip test of the friction locks against twice the 45 N·m worst torque.
10. Decision 3 (docs): TRL 4 test plan: weigh the prototype against R16 (45 kg), with the 5 mm yoke plates and lighter holder arms ready.
11. Decision 2 (pictures): At the next render session on Amish's Mac, redraw the photoreal renders, card and social preview to the constructable design (yoke plates, axle plates, holder and stand).

### Points found in the review

Raised when the recommendations were written (2026-10-01) and not yet acted on:

- Item 1 is a precondition for the whole pressure system: nothing should be pressurised until it is decided, as the register says.
- The value-engineering figure (USD 497 against USD 450) excludes USD 45 of validation consumables; that is consistent with the target, but the consumables are a recurring cost per batch of tests.
- Renders still show the concept tube yoke, quadrant, bearing blocks, holder and stand.

## 2026-10-02: photoreal renders redone on the constructable design

Rendered with Blender Cycles on Amish's Mac from the updated appearance model; captioned with `.kit/photo_caption.py`; `media/card.png` and `media/social-preview.png` regenerated with `.kit/cards.py`. Views: hero, exploded, detail. image_qc passes. Appearance deviations are those logged above as proposed, awaiting Amish.

## 2026-10-03: decisions recorded

Amish decided on 2026-10-03: "TIght Margins - i accept the margins". For SunClave this is the R16 margin of 0.2 kg (about 44.8 kg against 45 kg); the prototype is weighed at TRL 4 with a canner of 5.0 kg or less.

- `docs/06-design-decisions.md` (SCL-DEC-001) and `docs/03-requirements.md` (SCL-REQ-001) updated.

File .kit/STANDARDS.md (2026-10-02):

---
doc_id: OHP-STD-001
title: Documentation and drawing standard
project: Open Hardware Portfolio
doc_type: Standard
version: "1.7"
status: Released
date: 2026-09-30
author: Amish Chadha
license: CC-BY-SA-4.0
revisions:
  - version: "1.0"
    date: 2026-09-24
    author: Amish Chadha
    change: First release of the standard
  - version: "1.1"
    date: 2026-09-24
    author: Amish Chadha
    change: Adopt Technology Readiness Levels (section 9) for project maturity
  - version: "1.2"
    date: 2026-09-24
    author: Amish Chadha
    change: Portfolio phase cap (section 10), concept media standard (section 11), CLAUDE.md guardrails
  - version: "1.3"
    date: 2026-09-24
    author: Amish Chadha
    change: Scale figure, interactive 3D viewer and flow diagrams added to concept media; session slash commands
  - version: "1.4"
    date: 2026-09-26
    author: Amish Chadha
    change: Every sheet and render names the project and its GitHub repository; overall dimensions, ISO centre lines and 300 dpi PNG on sheets; titles name the device and view labels state the viewing direction; optional photoreal renders with Blender
  - version: "1.5"
    date: 2026-09-27
    author: Amish Chadha
    change: Product renders (section 12), storefront images and image quality check (section 13), public release and release gate (section 14), authorship, citation and commit signing (section 15)
  - version: "1.6"
    date: 2026-09-29
    author: Amish Chadha
    change: Licensing metadata with REUSE (section 16), Zenodo DOI and Software Heritage archiving (section 17), release gate checks REUSE and a single CITATION.cff license, archive.py
  - version: "1.7"
    date: 2026-09-30
    author: Amish Chadha
    change: Concept and constructable design states; design decisions register (DEC) kept apart from the build plan; prototype build plan (BLD, section 18) with pictures by component is required TRL 3 evidence; every repo targets TRL 3 during the populate phase; build_views.py; /to-trl3 and /build-plan commands
---

# Documentation and drawing standard

Every project in the portfolio uses this standard, so that each precis, write-up and sketch looks the same and carries its own version history. The standard ships as a kit in each repo's `.kit/` folder. The kit version is in `.kit/KIT_VERSION`.

## 1. Document types and IDs

Every controlled document has a unique ID in the form `PRJ-TYP-NNN`.

- `PRJ` is the three-letter project code listed in section 7.
- `TYP` is the document type code from the table below.
- `NNN` is a sequence number within that project and type, starting at 001.

| Code | Type | Typical file |
| --- | --- | --- |
| PRC | Design precis | `docs/02-concept.md` |
| PRB | Problem statement | `docs/01-problem.md` |
| REQ | Requirements | `docs/03-requirements.md` |
| CAL | Calculation or sizing note | `docs/04-calcs/*.md` |
| DDR | Design decision record | `docs/decisions/*.md` |
| BOM | Bill of materials | `bom/bom.csv` |
| DWG | Drawing or sketch sheet | `cad/drawings/*.svg` |
| BLD | Prototype build plan (section 18) | `docs/05-build-plan.md` |
| DEC | Design decisions register (section 18) | `docs/06-design-decisions.md` |
| TST | Test plan or test report (front matter adds `environment: lab` or `relevant`) | `docs/05-tests/*.md` |

Example: `TBK-PRC-001` is the ThermaBrick design precis.

## 2. Revision scheme

| Artifact | While in draft | When released | Change after release |
| --- | --- | --- | --- |
| Documents | 0.1, 0.2, 0.3 ... | 1.0 | 1.1 for minor edits, 2.0 for a design change |
| Drawings | Rev P1, P2 ... (preliminary) | Rev A | Rev B, C ... |

- Every change to a controlled document adds a row to its revision history before the commit.
- The `version` field in front matter always equals the newest row in `revisions`. The renderer rejects a document where they differ.
- Status is one of `Draft`, `In review`, `Released` or `Superseded`. Draft and In review documents print with a status band on every page.
- Every release is tagged in Git as `<doc_id>/v<version>`, for example `TBK-PRC-001/v1.0`. Drawings are tagged `TBK-DWG-001/revA`.
- Git history is the full audit trail. The in-document revision table is the human-readable summary.

## 3. Document front matter

Every Markdown document under version control starts with this block:

```yaml
---
doc_id: TBK-PRC-001
title: ThermaBrick design precis
project: ThermaBrick
doc_type: Precis
version: "0.1"
status: Draft
date: 2026-09-24
author: Amish Chadha
license: CERN-OHL-S-2.0
revisions:
  - version: "0.1"
    date: 2026-09-24
    author: Amish Chadha
    change: Initial draft
---
```

Quote version numbers so YAML keeps `1.0` as text instead of turning it into a number. List revisions newest last.

## 4. Writing style

- Chicago Manual of Style.
- No em dashes. Restructure the sentence instead.
- Lead each section with its conclusion, then support it.
- SI units throughout, in the form `12 kW`, `450 °C`, `3.2 m`. Imperial values may follow in parentheses.
- Number every figure and table ("Figure 2", "Table 1") and give each a caption.
- State every assumption in the calculation that depends on it.
- Put safety notes in a blockquote starting with **Safety:**.

## 5. Visual identity

| Element | Specification |
| --- | --- |
| Typeface | IBM Plex Sans for text, IBM Plex Mono for code and values (SIL Open Font License, bundled in `.kit/fonts`) |
| Ink | `#111827` |
| Secondary text | `#4B5563` |
| Rules and grid | `#D1D5DB` |
| Accent (one only) | `#0F766E` teal |
| Document page | US Letter, 20 mm margins |
| Drawing sheet | ANSI B landscape (431.8 x 279.4 mm) |
| Footer | Document ID, version, status, license and designmolecule.com on every page |

## 6. Drawing and sketch conventions

- Units are millimeters unless the title block says otherwise.
- Third-angle projection, marked with the symbol in the title block.
- Line weights: visible outlines 0.5 mm, hidden lines 0.25 mm dashed, center lines 0.18 mm chain.
- The title block contains the project, title, drawing number, revision, scale, units, projection, sheet, author, date, material or notes, and license.
- Every sheet and every render names the project and its GitHub repository (from `repo:` in `project.yaml`), at the top of the sheet and in the title block, so a printed or forwarded sheet is never anonymous.
- The drawing title names the device, not only the drawing type (for example "Handheld near-infrared resin scanner: general arrangement").
- Every view label states its scale and viewing direction (for example "Scale 1:1; side elevation looking along +Y"), and every isometric or render states where it is seen from.
- Orthographic views generated with `add_ortho` carry overall dimensions (length and depth on the top view, height on the front view) and ISO 128 centre lines on cylinders; hidden lines are dashed. Tolerances are not shown before TRL 4.
- Sheets are exported as SVG, PDF and a 300 dpi PNG.
- The revision table in the top right of the sheet lists every revision.
- Concept sketches use the same sheet and title block and carry the label "CONCEPT, NOT FOR FABRICATION".
- Geometry comes from `cad/src/*.py` (build123d). Sheets are generated by `.kit/drawing.py` and never edited by hand.

## 7. Project codes

| Code | Project | Code | Project | Code | Project |
| --- | --- | --- | --- | --- | --- |
| TBK | ThermaBrick | PCF | PicoFlow | HLT | HelioLite |
| CCB | CharCube | DRN | DustRunner | TRT | TremorTrace |
| STC | StepCue | FXH | FlexHand | CPD | ColdPod |
| SCL | SunClave | STR | SteamRoot | GGD | GrainGuard |
| SDL | SeedLine | ZBX | ZeerBox | RMS | RootMesh |
| DWD | DewDrive | SSK | StillStack | PPR | PotPress |
| WWT | WaterWatch | LMF | LumaFlow | FCL | FieldCell |
| CNP | ConePro | CVC | CulvertCrawl | EGD | EmberGuard |
| SNF | SnapFrame | CGM | CargoMule | SCM | StepClimber |
| SWC | SwapCell | PLP | PalletPilot | FTK | FlatTrike |
| WWK | WaterWalker | GRR | GrowRider | SSP | SunSpoke |
| SGN | StepGen | PBX | PowerBox | WML | WasteWise-ml |
| WSC | WasteWise Scan | RFE | ReflowEconomy | | |
| OHP | Portfolio-wide | | | | |

## 8. Build and publish

- `python .kit/render.py` checks every controlled document and renders it to `docs/pdf/<doc_id>_v<version>.pdf`.
- `python .kit/drawing.py` (called from each project's `cad/src/sheets.py`) builds drawing sheets as SVG and PDF in `cad/drawings/`.
- The GitHub Action in `.github/workflows/docs.yml` runs the checks on every push and attaches PDFs to a GitHub Release whenever a release tag is pushed.
- Public releases follow section 14: `python .kit/release_gate.py` must pass, and the release tag is `v0.<TRL>.0` (for example `v0.3.0` at TRL 3).

## 9. Technology Readiness Level (TRL)

Each project states its maturity as a Technology Readiness Level on the NASA and US DOE 1 to 9 scale. The TRL rates this specific design, not the underlying technology. A sand battery is commercial elsewhere, but a new sand battery design starts at TRL 2 until evidence shows otherwise.

| TRL | Definition | Evidence the repo must contain |
| --- | --- | --- |
| 1 | Basic principles observed | Problem statement (PRB) |
| 2 | Technology concept formulated | Draft precis (PRC) and requirements (REQ) |
| 3 | Analytical or experimental proof of concept | Calculation note (CAL), working build123d model with STEP export, drawing sheet (DWG), priced BOM with every unit cost filled in, prototype build plan (BLD) with pictures, `design_state: constructable` |
| 4 | Components validated in the lab | Test report (TST) with `environment: lab`, build log entries |
| 5 | Validated in a relevant environment | Test report (TST) with `environment: relevant` |
| 6 | System prototype demonstrated in a relevant environment | Precis at version 1.0 or later with status Released, a drawing at a lettered revision (Rev A or later), and a system-level TST with `environment: relevant` |
| 7 to 9 | Operational demonstration through proven in service | Beyond portfolio scope; claim only with a named deployment partner and evidence |

Rules:

- `project.yaml` records `trl` (current level), `trl_target` (the level the current effort aims for) and `trl_evidence` (the files that support the claim).
- `python .kit/render.py --check` fails if the evidence for the claimed TRL is missing. CI runs this check on every push.
- Documentation alone cannot go past TRL 3. TRL 4 and above require hardware and a test report.
- TRL and visibility are independent. A repo can be public at TRL 3 as a documented design ready to build.
- A change of TRL is recorded in the build log with the date and the evidence that justified it.

## 10. Portfolio phase and TRL cap

`.kit/PHASE.yaml` sets the current phase. During the **populate** phase every repo is capped at **TRL 3**: `trl` and `trl_target` may not exceed 3, and the check fails if they do. Every repo targets the cap: `trl_target` must equal 3, so a new repo is taken all the way to TRL 3 (scaffold, populate and advance, see `/to-trl3`). Work that belongs to TRL 4 or later (building or testing hardware, test articles, test plans and reports, build-log entries, purchasing lists, PCB layouts) must not be started. The prototype build plan (BLD, section 18) is TRL 3 paper work and is required. Where it already exists it is kept, flagged in the check output, and not extended. Only Amish changes `PHASE.yaml`.

Every repo carries a `CLAUDE.md` with the working rules for AI sessions: the TRL cap, decision rights (nothing is recorded as decided unless Amish decided it), one step per session, and a mandatory `docs/REVIEW.md` before stopping.

## 11. Concept media

Every repo at TRL 2 or above explains its idea visually. Media are generated from a build123d massing model with `.kit/concept.py`, never drawn by hand, so they stay in step with the design.

| File | Required | Purpose |
| --- | --- | --- |
| `media/hero.png` | TRL 2+ | Shaded isometric render with a 1.75 m person for scale; the website card image |
| `media/concept-blueprint.png` and `.pdf` | TRL 2+ | Blueprint concept sheet: orthographic and isometric views, scale, key figures, title block |
| `media/model.glb` and `media/viewer.html` | TRL 2+ | Interactive 3D viewer (glTF plus model-viewer) for the website |
| `media/cutaway.png` | When the inside matters | Section view showing internal parts |
| `media/exploded.png` | Recommended | Exploded view with numbered callouts matching the BOM |
| `media/flow.png` | When energy or material moves | System, energy or material flow diagram with losses |

Session commands in `.claude/commands/` (`/populate`, `/advance-trl3`, `/rein-in`, `/refresh-media`) carry the standard prompts, so every Claude Code session starts from the same instructions.

At TRL 2 a massing model is enough: correct overall proportions and main components. All concept media carry "CONCEPT, NOT FOR FABRICATION". The check warns when required media are missing at TRL 2 and fails at TRL 3.

## 12. Product renders

Every repo at TRL 3 shows the product as it would look, not only as a massing model.

- `cad/src/product_model.py` is the appearance model. It defines `product_parts()` (named parts with a shape and a material), `TITLE` ("Name: what it is") and `RENDER_VIEWS`. It is for renders only: every main dimension comes from `cad/src/model.py`, never typed in again.
- Where the appearance model departs from `model.py` (a chamfer, a label, a fastener drawn for realism), record the deviation in `docs/REVIEW.md` as "Proposed, awaiting Amish".
- Scale comes from context, not from a floating figure: a hand or forearm for handheld objects, and the posed mannequin (`mannequin()` in `.kit/context_parts.py`: stand, walk, push, ride, sit, reach) for anything a person uses at body scale.
- Renders are made with `.kit/export_views.py` (one scene per view) and `.kit/photoreal.py` (Blender Cycles), then captioned with `.kit/photo_caption.py`. Files are `media/render-<view>.png`; `media/render-hero.png` is required.
- Every caption names the project, the repository and the viewing direction, and carries "CONCEPT, NOT FOR FABRICATION".
- Captions never sit on the render. `.kit/photo_caption.py` adds a header band (title, concept label, repository) above the render and a footer band (view note) below it, wraps every line to the image width, and steps the font down to a floor before adding a line.
- The README opens with `media/render-hero.png`.
- Software-only and scene repositories (no single product) may use a scene render as the hero instead of a product model.
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

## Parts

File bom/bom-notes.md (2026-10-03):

# BOM notes

Prices are indicative estimates by supplier type (TRL 3), not quotes; they will be confirmed with named suppliers once a partner area is chosen. Row numbers match the exploded view (`media/exploded.png`) and the model (`cad/src/model.py`). Items 7 and 12 have no separate cost; items 17 to 21 are not modelled.

Value-engineering target: USD 450 (`budget_usd` in `project.yaml`, a hypothetical control target, not a limit). Estimated cost of the constructable design (every line except 18): **USD 528**, USD 78 over the target. The total is computed from this file by `docs/04-calcs/sizing.py`.

Changes at TRL 3:

- Decided cuts (SCL-DDR-001 item 2): timber stand instead of steel tube (item 4, $55 to $40), OLED instead of e-paper (item 14), and a USB power bank instead of the 5 W panel and 18650 cell (item 15, $18 to $12). Together with the TRL 2 prices these save about $29, short of the $37 needed to reach $400, so the budget rose to $450.
- Item 13, basket: resized to 250 x 150 mm on a 40 mm trivet, because 270 x 180 mm does not fit a 12 L cooker (SCL-CAL-001 section 1).
- Item 14, logger: a 0.05 % reference resistor on the Pt100 interface (needed for R7) and a 16-bit ADS1115 converter for the pressure transducer are included in the $58.
- Items 19 and 20, eye protection and a parking cover: added for R9 and R11 ($22).
- Item 9: seat bore 4 mm or more specified from the relief capacity check (SCL-CAL-001 section 8).

Item 18 (chemical and biological indicators, about $45) is not in the parts total because it is needed only for testing at TRL 4 and later, which is on hold by Amish's instruction.

Changes from Amish's acceptance of the recommendations (SCL-DDR-002, 2026-09-25):

- Item 4: all four castors lock instead of two ($40 to $44; item 16).
- Item 14: a 0 to 300 kPa absolute transducer with an overpressure rating of 600 kPa or more instead of 0 to 500 kPa, at a similar price (item 18). The 12 min retarget reminder and the trim reminder are firmware rules for the existing buzzer and display (items 13 and 17).
- Item 21: keep-out marking for the restated R11 ($6; item 15).

These add $10, from $430 to $440. How BOM items 8 to 10 are mounted on the lid (item 5) was decided on 2026-10-02: the lid is not drilled; item 6 becomes a pressure canner sold with a factory gauge and relief valve, and the probe gland (item 10) goes on an adapter plate on the vent stem with a bore of 3 mm or more. Items 6 to 10 were respecified and repriced on the same day (below).

Changes for the constructable design (SCL-DDR-003, 2026-10-01, accepted by Amish on 2026-10-02, with a back-up drop pin to be added to item 3), USD 440 to USD 497:

- Item 1: petals with folded flanges and rim tabs, riveted (price unchanged).
- Item 2: ribs at 15 degree offsets, 25 x 4 mm rim band, 200 x 4 mm hub plate and 24 rib clips (USD 30 to 36).
- Item 3: yoke plates with lock fans, rim stand-offs, lock studs and star knobs replace the tube arms, collars, lever and quadrant (USD 18 to 30).
- Item 4: bolted timber stand with side rails on edge and lapped braces, steel axle plates, axles and collars, foot brackets, real 102 mm castors (USD 44 to 58).
- Item 5: flat holder ring cut from plate, arms carried on the upright tops, arm brackets (USD 12 to 17).
- Item 14: a box large enough for the power bank, the transducer on the lid fittings, plug-in sensor leads and the thermocouple band clamp (USD 58 to 66).
- Item 16: gnomon bracket on the rim band (USD 2 to 4).
- Item 17: more bolts for the bolted joints (USD 15 to 25).

Changes carrying the decisions of 2026-10-02 into the design (SCL-DDR-001 item 5 and SCL-DDR-003 A2), USD 497 to USD 528:

- Item 6: a pressure canner of about 12 L sold with a factory gauge and relief valve replaces the household cooker (USD 55 to 100, indicative for a 12 to 15 L canner sold with a gauge). Mass about 4.8 kg with its fittings (indicative; confirm when bought).
- Item 7: the canner's lid; its vent pipe moves up onto the adapter plate; the lid is not drilled.
- Items 8 and 9: now the canner's factory-fitted gauge and relief valve, supplied with item 6 (USD 15 and USD 20 removed).
- Item 10: a stainless vent-stem adapter plate in the lid's vent-pipe hole, with the gland and probe, replaces the lid gland and tee (USD 30 to 45).
- Item 3: two drop pins on stainless lanyards with eye screws, and a row of pin holes in each yoke plate fan (USD 30 to 36).
- Item 4: axle plates 285 mm long with a short slot for the drop pin (price unchanged).

The main cost drivers and the savings worth trying are in the design decisions register (`docs/06-design-decisions.md`, Value engineering).

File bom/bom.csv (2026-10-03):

item | qty | spec | supplier | unit_cost_usd | make_buy | notes
1 Reflector petals | 12 | Polished or anodized aluminum reflector sheet 0.5 mm, reflectance 85 % or more, cut to 12 gores for a 1.4 m paraboloid, focal length 500 mm, each with a 12 mm flange folded down along both long edges and two 30 x 12 mm tabs folded down at the rim (about 1.9 m² of sheet with offcuts); 3.2 mm aluminium rivets | Aluminum stockist or solar reflector sheet supplier | 6.25 | make | Indicative price (about $75 for the set); SK14-style petal layout; flanges and tabs added for fixing (SCL-DDR-003)
2 Dish ribs rim hub and clips | 1 | 12 steel flat-bar ribs 20 x 3 mm bent on edge to the paraboloid profile in a plywood jig; rim band of 25 x 4 mm flat bar rolled to 1,408 mm outside diameter; hub plate 200 mm x 4 mm; 24 rib clips cut from 20 x 20 x 3 mm angle; M5 bolts | Local steel stockist | 36.00 | make | Indicative material cost; bending jig needed; ribs at 15 degrees plus 30 degree steps; clips added (SCL-DDR-003)
3 Tilt yoke, locks and drop pins | 1 | Two yoke plates cut from 6 mm steel plate (hub, arm to the rim and a fan with a 140 mm radius lock slot and a row of eleven 8.5 mm drop pin holes on a 163 mm radius, 7.5 degrees apart); two rim stand-offs of 50 x 25 x 2.5 mm rectangular steel tube 101 mm long with M8 countersunk screws; two M10 x 80 lock studs with star knobs and washers; two 8 mm zinc-plated steel drop pins about 40 mm long with ring heads, each on a 300 mm stainless wire lanyard tied to the axle plate; dish-axis elevation 15 to 90 degrees | Local steel stockist | 36.00 | make | Indicative material cost; replaces the tube arms, collars, lever and quadrant of the concept (SCL-DDR-003); drop pins and lanyards added as the back-up stop (decided 2026-10-02, SCL-DDR-003 A2), about $3 each from a hardware or fastener shop
4 Timber stand with castors | 1 | Treated timber: two cross rails 70 x 35 mm x 1,805 mm laid flat; two side rails 45 x 70 mm x 1,100 mm on edge; two uprights 45 x 70 mm x 892 mm; four braces 45 x 35 mm x 640 mm. Two axle plates 6 x 70 x 300 mm steel, each with a short arc slot for the drop pin and a 5 mm lanyard hole; two 20 mm steel axles 85 mm long with four shaft collars; four galvanised 50 x 50 mm angle brackets; four 75 mm locking swivel castors, 102 mm mounting height, with brake pedals | Timber yard and hardware shop | 58.00 | make | Timber replaces steel tube (SCL-DDR-001 item 2); all four castors lock (SCL-DDR-002 item 16); about $16 timber, $20 castors, $22 steel and brackets; joints and axles added (SCL-DDR-003); axle plates 30 mm longer for the drop pin slot (2026-10-02), price unchanged
5 Level pot holder | 1 | Flat ring cut from 4 mm steel plate, 348 mm inside and 408 mm outside diameter, under the cooker handles; two 25 x 25 x 2 mm steel square tube arms 687 mm long resting on the uprights; two 40 x 40 x 4 mm angle brackets; fixed, does not tilt | Local steel stockist | 17.00 | make | Indicative material cost; ring cut by jigsaw or a local cutting shop (SCL-DDR-003)
6 Pressure canner | 1 | Pressure canner of about 12 L, aluminium, sold with a factory dial gauge, a factory relief (safety) valve, a 103 kPa (15 psi) weighted regulator on a vent pipe and an overpressure plug, rated by its maker for 103.4 kPa; inside about 280 mm diameter x 200 mm deep and handles about 229 mm from the centre (to be confirmed for the chosen model); base and lowest 80 mm of wall painted with high-temperature matte black | Canning, household goods or farm supply store | 100.00 | buy | Indicative price for a 12 to 15 L canner sold with a gauge (about $80 to $130 by supplier type); replaces the household cooker and the separate gauge and relief valve (decided 2026-10-02, SCL-DDR-001 item 5); the maker's lid is not drilled and nothing is welded or changed on the vessel
7 Canner lid with weighted regulator | 1 | Supplied with item 6: lid, weighted regulator, vent pipe and overpressure plug; carries the factory gauge and relief valve (items 8 and 9) and, on its vent-pipe hole, the adapter plate (item 10) | Supplied with item 6 | 0.00 | buy | Cost in item 6; the maker's vent pipe screws into the top of the adapter plate, so the regulator sits about 50 mm higher; the overpressure plug is left untouched
8 Pressure gauge (factory-fitted) | 1 | The canner maker's dial gauge, as supplied on the lid; reads without power | Supplied with item 6 | 0.00 | buy | Cost in item 6; was a separate 100 mm stainless gauge ($15) until 2026-10-02; have the gauge checked against a reference before first use, as canner makers advise
9 Relief valve (factory-fitted) | 1 | The canner maker's relief (safety) valve, as supplied on the lid; seat bore 4 mm or more and set pressure 125 kPa gauge or less to be confirmed for the chosen model | Supplied with item 6 | 0.00 | buy | Cost in item 6; was a separate brass spring valve ($20) until 2026-10-02; SCL-CAL-001 section 8
10 Vent-stem adapter plate gland and Pt100 probe | 1 | Stainless steel adapter plate 84 x 40 x 20 mm with a threaded spigot and nut for the lid's vent-pipe hole and a high-temperature gasket on the lid boss; 6 mm bore from the vent hole (5.2 mm equivalent bore round the probe, 3 mm or more required) with ports for the maker's vent pipe, the gland and the pressure transducer; 1/8 in NPT compression gland for a 3 mm probe; Pt100 class A, 3 mm x 150 mm, PTFE leads | Local machine shop and instrument supplier | 45.00 | buy | Indicative price: about $15 for the machined plate, gasket and nut and $30 for the gland and probe; the adapter replaces the lid tee and pigtail (decided 2026-10-02, SCL-DDR-001 item 5)
11 Insulated jacket | 1 | Mineral wool blanket 25 mm with aluminized glass cloth skin on the upper wall; lowest 80 mm of wall and the base left bare | Insulation supplier | 12.00 | make | Indicative price
12 Water charge | 1 | 1.5 L of clean water per cycle, boiled or distilled where available | Site supply | 0.00 | buy | Consumable; no cost
13 Instrument basket and trivet | 1 | Stainless wire basket 250 mm diameter x 150 mm deep on a 40 mm trivet that keeps the load above the water | Kitchen or lab supplier | 14.00 | buy | Indicative price; resized from 270 x 180 mm to fit the 12 L cooker (SCL-CAL-001)
14 Cycle logger | 1 | ESP32-class board, MAX31865 Pt100 interface with 0.05 % reference resistor, ADS1115 16-bit ADC, 0 to 300 kPa absolute stainless ratiometric pressure transducer with an overpressure rating of 600 kPa or more, K-type thermocouple on a stainless band clamp at the base edge (boil-dry alarm), RTC, microSD, 1.3 in OLED display, buzzer, IP65 box about 180 x 80 x 65 mm with the power bank inside, sensor cable with plugs at the lid and the box | Electronics distributor | 66.00 | buy | Indicative price (transducer about $18); OLED replaces e-paper (SCL-DDR-001 item 2); 0 to 300 kPa span (SCL-DDR-002 item 18); larger box and plug-in sensor leads added (SCL-DDR-003); firmware at TRL 3 only as a labeled sketch
15 Logger power bank | 1 | 10,000 mAh USB power bank with a low-current (always-on) mode, kept in the shaded logger box; recharged from any USB source | Electronics or phone accessory shop | 12.00 | buy | Replaces the 5 W panel and 18650 cell (SCL-DDR-001 item 2)
16 Sighting gnomon | 1 | Pin parallel to the dish axis over a 120 mm aluminum target plate, on a 40 x 40 x 4 mm angle bracket bolted to the outside of the rim band | Local fabricator | 4.00 | make | Indicative price; bracket added (SCL-DDR-003)
17 Hardware and consumables | 1 | Stainless or galvanised bolts, nuts and washers (M10 brace and plate bolts, M8 crossing, castor, bracket and stand-off bolts, M5 clip bolts), about 300 rivets, thread sealant rated for steam, high-temperature paint, cable ties | Local hardware shop | 25.00 | buy | Indicative price; more bolts for the constructable design (SCL-DDR-003); no exploded-view callout
18 Validation consumables | 1 | Class 5 chemical integrators (ISO 11140-1) and self-contained Geobacillus stearothermophilus biological indicators for commissioning and weekly checks | Medical supplier | 45.00 | buy | Not in the parts cost; used only at TRL 4 and later; no exploded-view callout
19 Eye protection | 2 | Shade 5 welding goggles or glasses for anyone near the focus (R11) | Safety equipment or welding supplier | 6.00 | buy | Indicative price; not modelled
20 Parking cover | 1 | Opaque cover with an elastic hem for the 1.4 m dish, fitted whenever the dish is parked (R9, R11) | Tarpaulin or canvas maker | 10.00 | buy | Indicative price; not modelled
21 Keep-out marking | 1 | 20 m roll of hazard barrier tape and four ground pegs to mark a 2 m keep-out around the dish and vessel (R11) | Hardware shop | 6.00 | buy | Indicative price; not modelled; added for the restated R11 (SCL-DDR-002 item 15)

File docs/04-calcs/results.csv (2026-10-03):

id | requirement | value | target | status | note
R1 | Sterilizing condition (redefined) | 120.95 C and 30.3 min at 0 m; 117.7 C and 63 min at 1,800 m | exposure equal to 20/30 min at 121 C (z = 10 C), 115 to 124 C, real temperature recorded | Not verifiable at TRL 3 | Temperature and hold met by calculation; a 103.4 kPa canner gives 120.95 C at sea level and less above it; equivalence needs biological indicators
R2 | Load capacity | basket 250 x 150 mm in a 12.3 L canner; 16 mm over the water | basket 250 x 150 mm or more; 2.0 kg | Met | Model check; TRL 2 basket 270 x 180 mm did not fit a 12 L cooker
R3 | Load type | solid instruments, unwrapped or single-wrapped | no lumened, hollow or textile loads | Met | By definition
R4 | Cycle time | 81 min central (72 to 111) | 90 min or less | At risk | Precedent 93 to 183 min heat-up (larger vessels)
R5 | Daily throughput | 4 (equator), 4 (15 N winter), 4 (600 W/m2) | 3 or more | Met | 09:00 to 15:00, warm restarts
R6 | Cycle record | 173 kB per cycle; about 23,148 cycles on 4 GB | 1 s logging; 1,000 cycles | Met | Design check
R7 | Measurement accuracy | 0.44 K with the 0.05 % reference (0.55 K with 0.1 %); pressure 3 kPa (0 to 300 kPa) | 0.5 K; 5 kPa | Met | With the 0.05 % reference now in the BOM; field check needs a barometer, not the logger's own transducer
R8 | Pressure safety | factory relief valve 5.2 x worst steam generation; vent 2.7 x; adapter bore 5.2 mm equivalent | relief 125 kPa gauge or less; vessel rated by its maker | Met | Canner with factory gauge and relief valve, lid not drilled (decided 2026-10-02); relief seat and set pressure and the vessel rating to confirm for the chosen model
R9 | Heat input control | power below 5 % at 15 deg of tilt | stop within 10 s; dish shaded when parked | Met | Parking cover added (item 20)
R10 | Boil-dry protection (restated) | 1.26 kg left (design); 0.81 kg at 1000 W/m2; with the trimming rule 1.31 kg at 1,800 m and 1.28 kg at 2,400 m, 1000 W/m2 | 0.5 L left in the design case and, with the trimming rule, at altitude; trim reminder; alarm at 140 C | Met | Untrimmed, 0.15 kg at 1,800 m; the rule depends on the operator (SCL-DDR-002 item 17)
R11 | Burn and glare protection (restated) | whole vessel and fittings treated as a hot zone; dish turned 15 deg off the sun before reaching in; parking cover, goggles and ground keep-out marking in the BOM | vessel and fittings a marked hot zone reached only with the dish off the sun; focus reached only through the dish; eye protection; keep-out marked | Met | By design review (SCL-DDR-002 item 15); no physical guard, which could not close the light cone without shading the dish
R12 | Air-removal check | uncertainty 0.64 K against the 2 K threshold | flag a hold more than 2 K below saturation | Met | 0 to 300 kPa transducer; sure to flag 8 % air; may flag from 4 %
R13 | Off-grid logger power (redefined) | 9 days on a 10,000 mAh bank | 3 days without charging; USB recharge | Met | Bank must not switch off at low load
R14 | Tracking effort (relaxed) | 90 % power held for 13 min | retarget no more often than every 12 min; logger reminder | Met | Worst-case sun motion 15 deg/h; relaxed from 15 min (SCL-DDR-002 item 13)
R15 | Stability | tipping factor 1.40 (worst, elevation 15 deg) | does not tip at 10 m/s | At risk | Sliding: 153 N wind vs 237 N grip on four locked castors; park face-up in high wind
R16 | Portability and build (relaxed) | 44.8 kg empty; largest piece 15.3 kg | 45 kg or less; pieces 20 kg or less; hand tools, drill, bolts | Met | Total relaxed from 40 kg (SCL-DDR-002 item 14); timber stand heavier than the TRL 2 steel estimate
R17 | Cost (redefined) | $528 | $450 value-engineering target for parts, validation consumables excluded | Over target by $78 | budget_usd is a hypothetical value-engineering target, not a limit; constructable design (SCL-DDR-003)

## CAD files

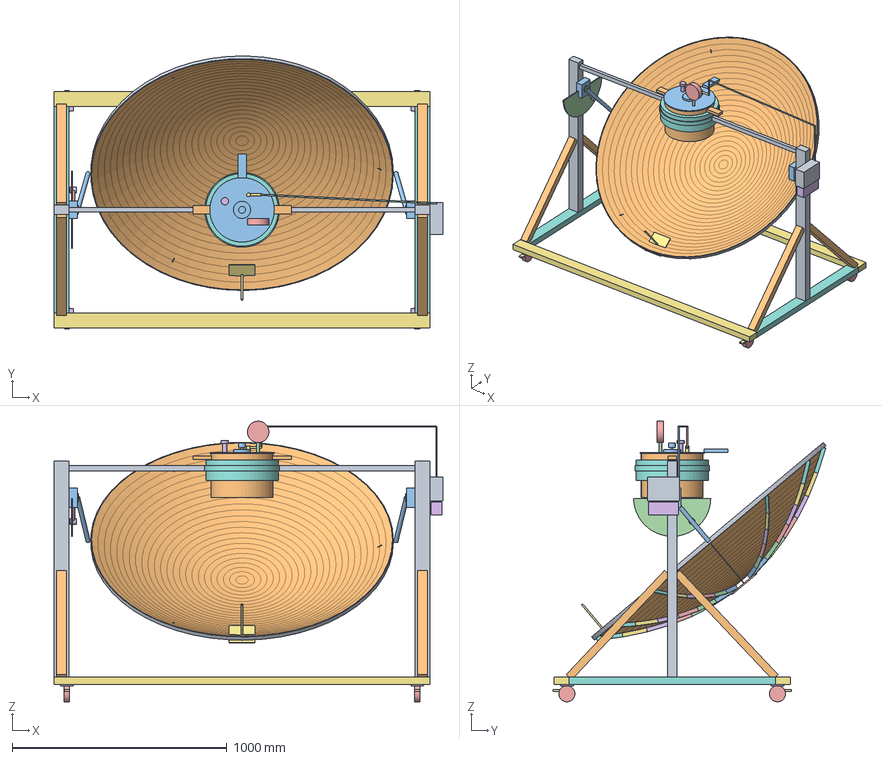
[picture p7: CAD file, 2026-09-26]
cad/step/sunclave-assembly.step
1810.0 x 1270.3 x 1306.0 mm

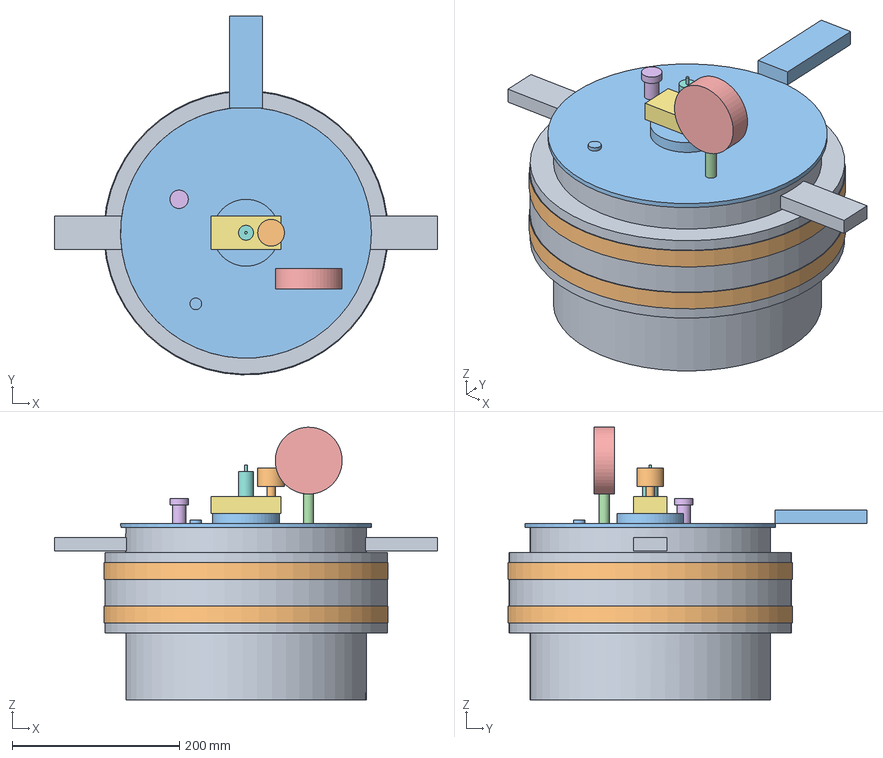
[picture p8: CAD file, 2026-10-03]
cad/step/sunclave-vessel.step
458.0 x 428.9 x 326.0 mm

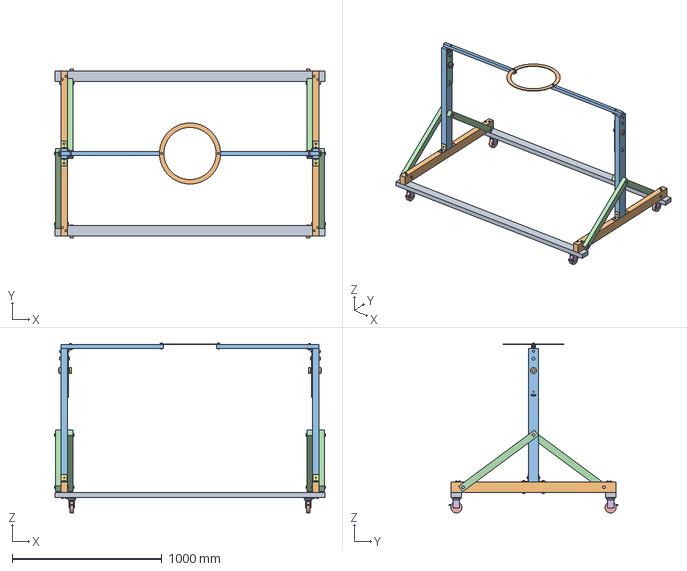
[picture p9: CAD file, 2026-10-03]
cad/step/sunclave-stand.step
1809.0 x 1126.0 x 1134.0 mm

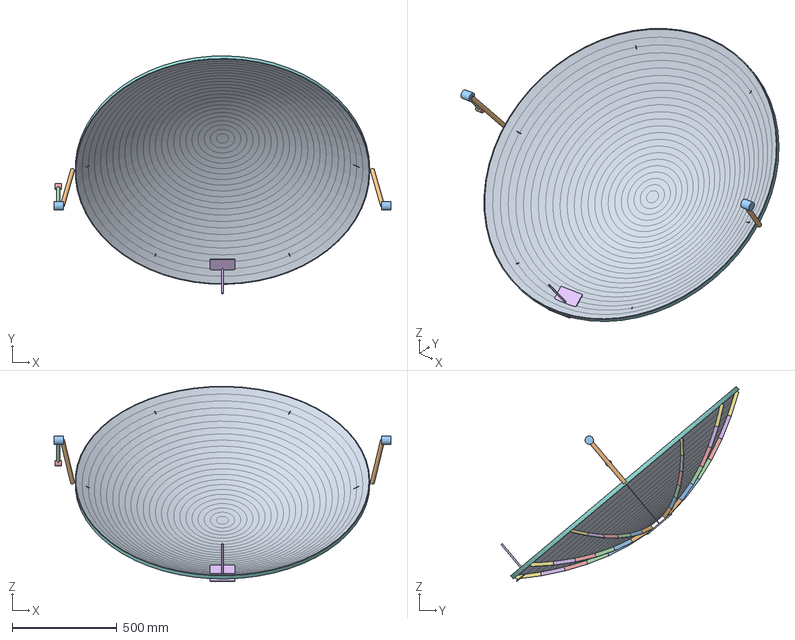
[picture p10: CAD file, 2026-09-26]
cad/step/sunclave-dish.step
1610.0 x 1137.7 x 933.1 mm

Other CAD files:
cad/stl/sunclave-assembly.stl
cad/stl/sunclave-dish.stl
cad/stl/sunclave-stand.stl
cad/stl/sunclave-vessel.stl

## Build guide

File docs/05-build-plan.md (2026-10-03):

---
doc_id: SCL-BLD-001
title: SunClave prototype build plan
project: SunClave
doc_type: Build plan
version: "0.3"
status: Draft
date: '2026-10-02'
author: Amish Chadha
license: CERN-OHL-S-2.0
revisions:
  - version: "0.1"
    date: '2026-10-01'
    author: Amish Chadha
    change: First build plan, with pictures by component and step; design made constructable (SCL-DDR-003)
  - version: "0.2"
    date: '2026-10-02'
    author: Amish Chadha
    change: "Safety stop S6: lid fittings as decided on 2026-10-02 (SCL-DEC-001)"
  - version: "0.3"
    date: '2026-10-02'
    author: Amish Chadha
    change: "Decisions of 2026-10-02 carried into the design: pressure canner with factory gauge and relief valve, vent-stem adapter plate (new section 3.21, SCL-DWG-120), back-up drop pins (new section 3.20, SCL-DWG-119; uprights, axle plates and yoke plates changed); pictures regenerated"
---

# SunClave prototype build plan

**Plan, not yet built.** How to build the first proof-of-concept prototype, component by component. Building and testing to it is TRL 4 work. Decisions still to be made are kept in the design decisions register ([docs/06-design-decisions.md](06-design-decisions.md)), not here.

SunClave is a research and educational prototype, not a medical device. This plan builds the dish, stand, holder, canner set-up and logger; it stops before the canner is ever put under pressure (safety stop S6).

## 1. What you are building

Figure 1. Every component, pulled apart and numbered in build order

*Figure 1. Every component pulled apart and numbered in build order; the dish is shown face up, as it is built.*

The prototype is a 1.4 m dish of twelve polished aluminium petals that turns on two axles between the uprights of a bolted timber stand on four locking castors, with a pressure canner of about 12 L hanging level at the focus by its handles from a steel ring, and a small logger in a box on one upright. Figure 1 shows the 20 component groups in the order you make or fit them. The made parts are the timber rails, uprights and braces; the steel axle plates, axles, ribs, hub plate, clips, rim band, stand-offs, yoke plates, holder arms, brackets and ring; the aluminium petals; the gnomon; the drop pins; and the insulated jacket. A local machine shop makes the small adapter plate that carries the temperature probe and pressure sensor on the canner's lid. The castors, the canner with its factory gauge and relief valve, the basket, logger modules, power bank and fixings are bought. The work is sawing and drilling timber; cutting, drilling, bending and filing steel bar and plate; cutting, folding and riveting thin aluminium sheet; and plugging bought electronic modules together. Nothing is welded, and the canner's lid is never drilled. The parts cost about USD 528 from the bill of materials.

> **Safety:** The finished dish concentrates sunlight to about 270 times normal at the focus: it burns skin in about a second, sets fire to paper, cloth and dry grass, and can blind. Keep the dish face down or covered whenever it is outdoors until section 6 says otherwise. The dish and yoke weigh about 16 kg and swing about the axles: two people lift it, and the tilt locks and drop pins are pinch points. Cut aluminium sheet and steel edges are sharp; deburr everything and wear cut-resistant gloves. Mineral wool sheds fibres; wear a dust mask and glasses when cutting the jacket. The canner is a pressure vessel; this plan never pressurises it.

## 2. What changed to make it buildable

The concept showed what SunClave does; some of its parts could not be made, fixed or assembled as drawn. Each change below keeps what SunClave does. They are recorded in decision record SCL-DDR-003, accepted by Amish on 2026-10-02 with the drop pin added, and, for the lid fittings, in SCL-DDR-001 item 5, decided on the same day.

*Table 1. Changes from the concept.*

| Component | The concept had | The buildable design has | Why |
| --- | --- | --- | --- |
| Pivots and tilt lock | Steel bearing blocks with stub axles, a quadrant plate and a lock lever, all drawn through each other | A steel axle plate on each upright, a fixed 20 mm axle, a PTFE washer and a 6 mm yoke plate that turns on the axle; a fan on each yoke plate with a slot that a star knob clamps, and a drop pin through a row of holes in the fan as a back-up stop (Figures 26, 27, 28 and 36) | A plain greased pivot is enough for a few degrees every 12 minutes; every part is cut, drilled and bolted; the pin holds the dish if a friction lock slips |
| Yoke to dish | Tube arms that stopped short of the rim | A short rectangular tube between the rim band and each yoke plate, clamped by two countersunk screws (Figure 24) | Two screws per side make the dish and yoke one rigid unit |
| Pot holder | A ring that ran through the jacket and sat below the handles | A flat steel ring the handles rest on, on two tube arms that sit on the upright tops and on brackets (Figures 31 and 33) | The canner hangs by its handles and lifts out without tools |
| Stand | Rails, uprights and braces butted together with no fixings; castors drawn shorter than real ones | Side rails on edge across the cross rails, uprights on angle brackets, braces lapped flat and bolted, real 102 mm castors (Figures 3, 6, 8 and 9) | Every timber joint is face to face and bolted; the stand comes apart in pieces of 6 kg or less |
| Dish frame | Ribs drawn into the sheet and not reaching the hub or rim; nothing for the petals to be riveted to | Petals with flanges folded down either side of each rib and riveted through it; clips at the hub and the rim; tabs riveted inside the rim band (Figures 14, 17, 18 and 20) | Rivets need a face to grip; clips are the simplest bolted joint for a bar standing on edge |
| Gnomon | On the reflector face, with no fixing | On a bracket bolted outside the rim band (Figure 22) | Shades no reflector and bolts to steel |
| Logger | Power bank hanging outside the box; no transducer on the tee | A box big enough for the bank, below the drop pin; the transducer on the adapter plate; plug-in sensor leads (Figure 35) | Matches the bill of materials; the lid comes off without cutting wires |
| Lid fittings | A household cooker with a gauge, relief valve and probe gland drawn on its lid and no way to fit them | A pressure canner sold with its own gauge and relief valve; the probe gland and pressure sensor on a small adapter plate in the lid's vent-pipe hole, with the maker's vent pipe and weight on top (Figure 37) | The maker's lid is never drilled, and the steam path stays at least as open as the maker's own vent |
| Build order | No order let the dish go between the uprights | A 2 mm gap at each pivot; one axle plate fitted after the dish is in (steps 11 to 13) | Two people can assemble it without lifting gear |

## 3. Making the components

Make and check each component before the assembly step that needs it. Sizes are in millimetres. "Left" and "right" are as seen standing in front of the stand, facing the reflector with the dish tipped toward you; the logger box is on the right. Workshop tolerance is 1 mm on timber and 0.5 mm on steel unless a step says otherwise; drawings do not carry tolerances before TRL 4. Treat every cut end and hole in timber with end-grain preservative.

### 3.1 Cross rails (make 2)

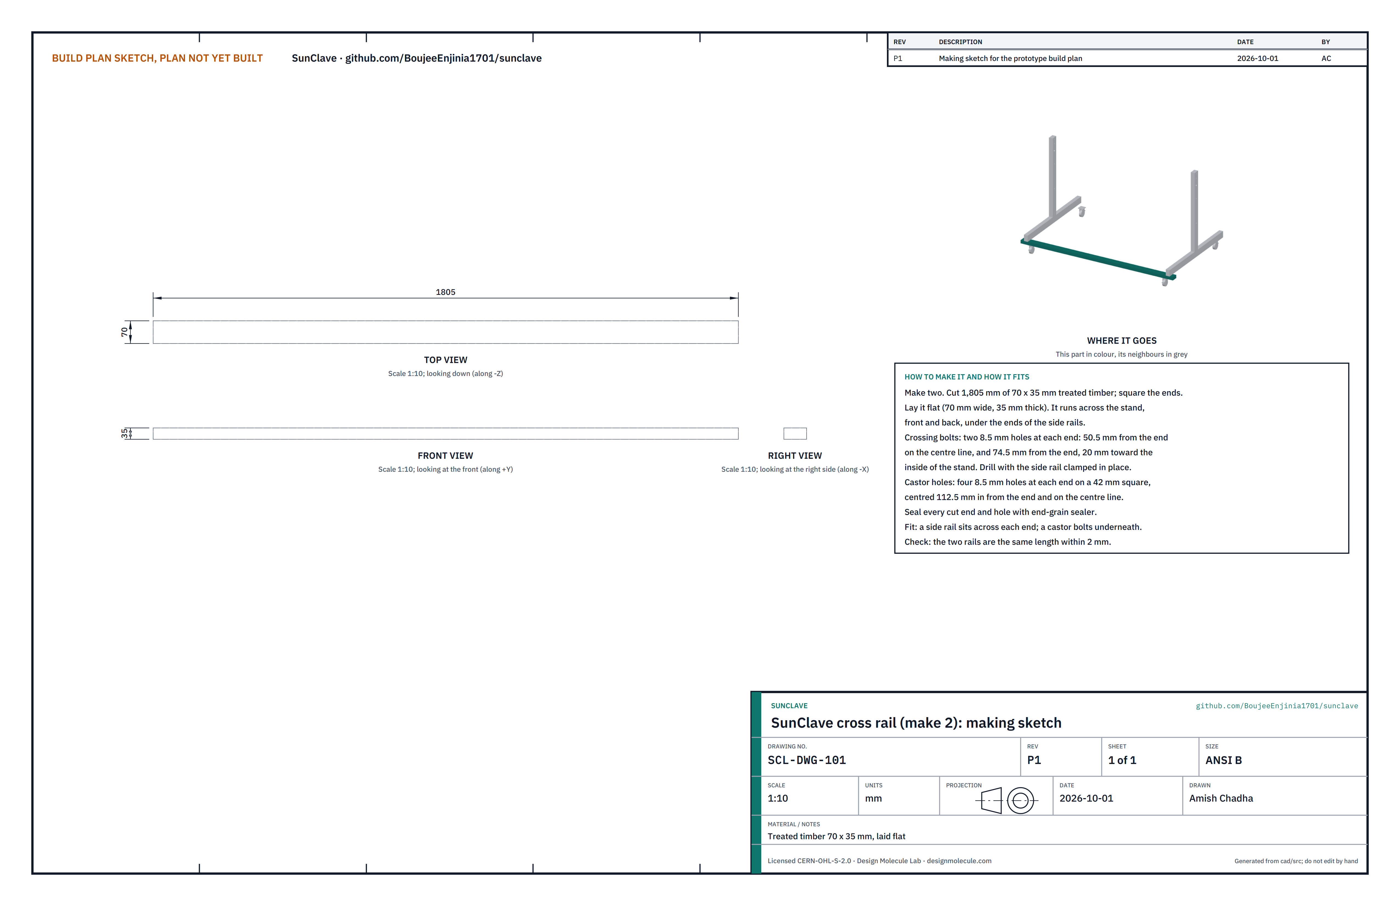
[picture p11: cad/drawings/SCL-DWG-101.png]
Figure 2. Making sketch of the cross rail


*Figure 2. Cross rail making sketch (SCL-DWG-101).*

**What it is and what it is made from.** The front and back members of the base, laid flat; each carries two castors underneath and the ends of both side rails on top. Treated timber 70 x 35 mm.

**How to make it.**

1. Cut 1,805 mm and square both ends.
2. At each end, drill the four castor holes, 8.5 mm, on a 42 mm square centred 112.5 mm from the end and on the centre line. Check against your castors' top plates first and move the holes to suit.
3. Leave the two crossing-bolt holes at each end until step 2 of the assembly, where you drill them through the side rail and cross rail together.

**How it fits the parts next to it.**

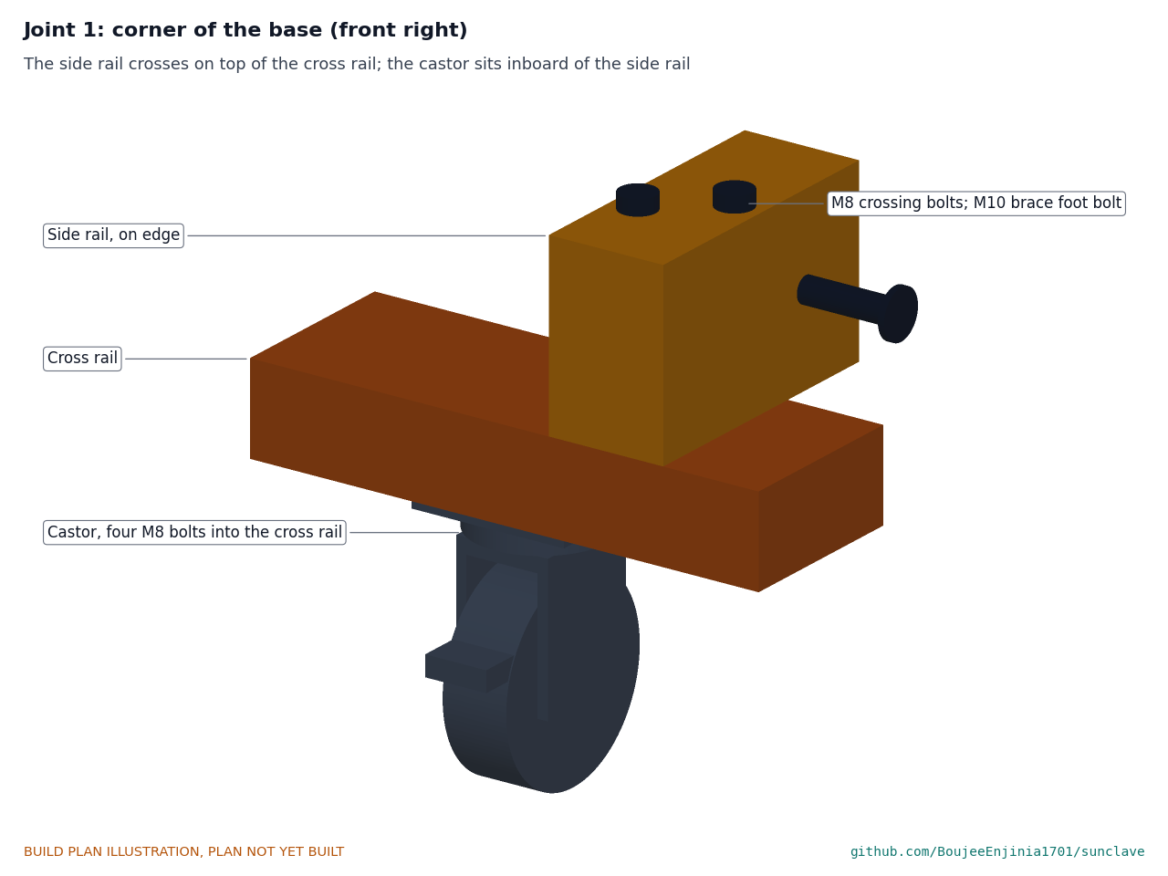
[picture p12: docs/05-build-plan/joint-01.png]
Figure 3. Joint 1: corner of the base


*Figure 3. The side rail, on edge, crosses on top of the cross rail; the castor bolts under the cross rail just inside the side rail.*

The castor's top plate sits flat on the underside, held by four M8 bolts with the nuts on top. Each side rail sits across the top, its outer face 40 mm in from the rail end, held by two M8 bolts through both.

**Check before moving on.** The two rails are the same length within 2 mm and lie flat on the floor without rocking.

### 3.2 Side rails (make 2)

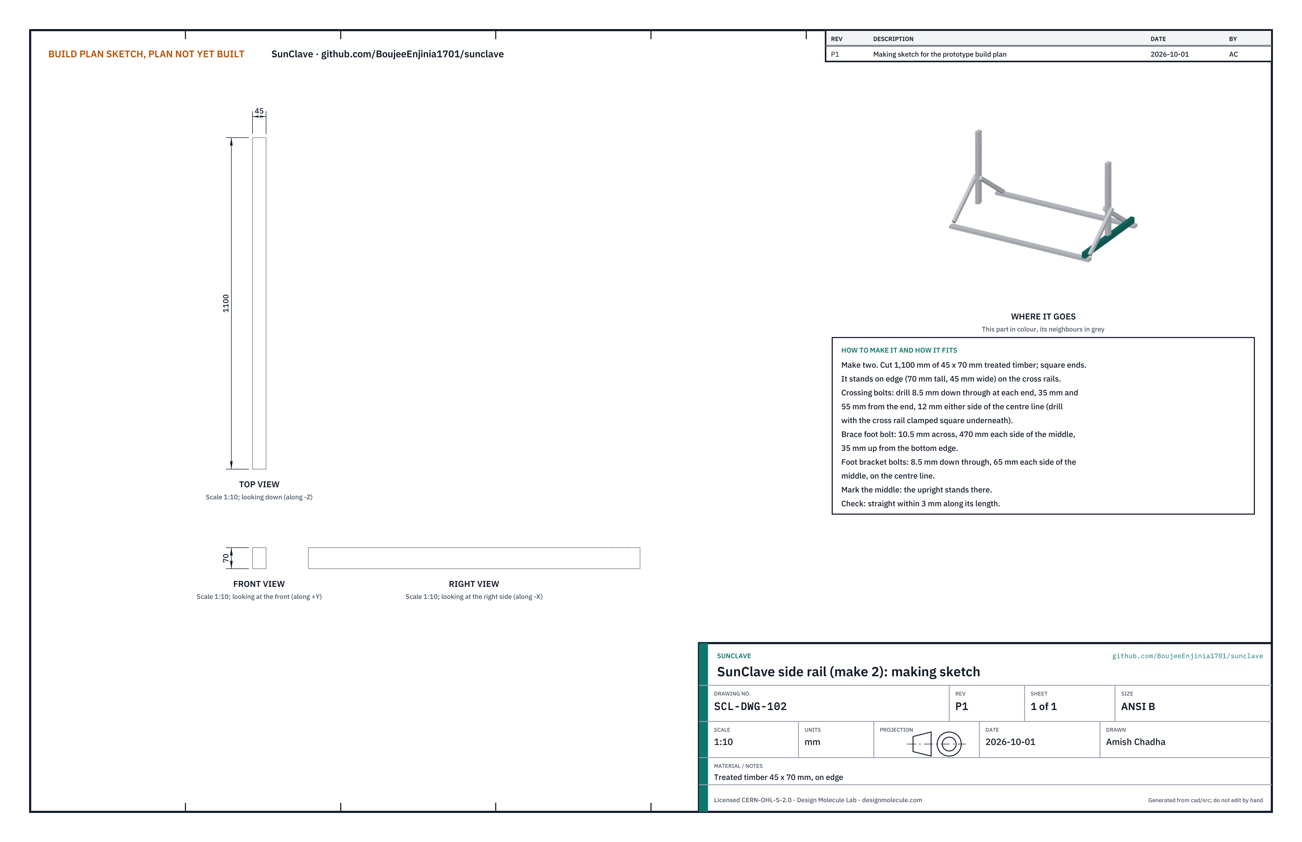
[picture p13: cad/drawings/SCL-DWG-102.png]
Figure 4. Making sketch of the side rail


*Figure 4. Side rail making sketch (SCL-DWG-102).*

**What it is and what it is made from.** The left and right members of the base, standing on edge; each carries an upright at its middle and the feet of two braces. Treated timber 45 x 70 mm.

**How to make it.**

1. Cut 1,100 mm, square both ends, and mark the middle on the top edge.
2. Brace foot holes: 10.5 mm across the 45 mm way, 470 mm each side of the middle, 35 mm up from the bottom edge.
3. Foot bracket holes: 8.5 mm down through, 65 mm each side of the middle, on the centre line.
4. Crossing holes: 8.5 mm down through at each end, at 35 and 55 mm from the end, 12 mm either side of the centre line. Drill these with the cross rail clamped square underneath (assembly step 2).

**How it fits the parts next to it.** It stands on edge across the ends of both cross rails. The upright stands on its middle; the braces lie flat on its outer and inner faces (Figures 8 and 9).

**Check before moving on.** Straight within 3 mm along its length.

### 3.3 Uprights (make 2)

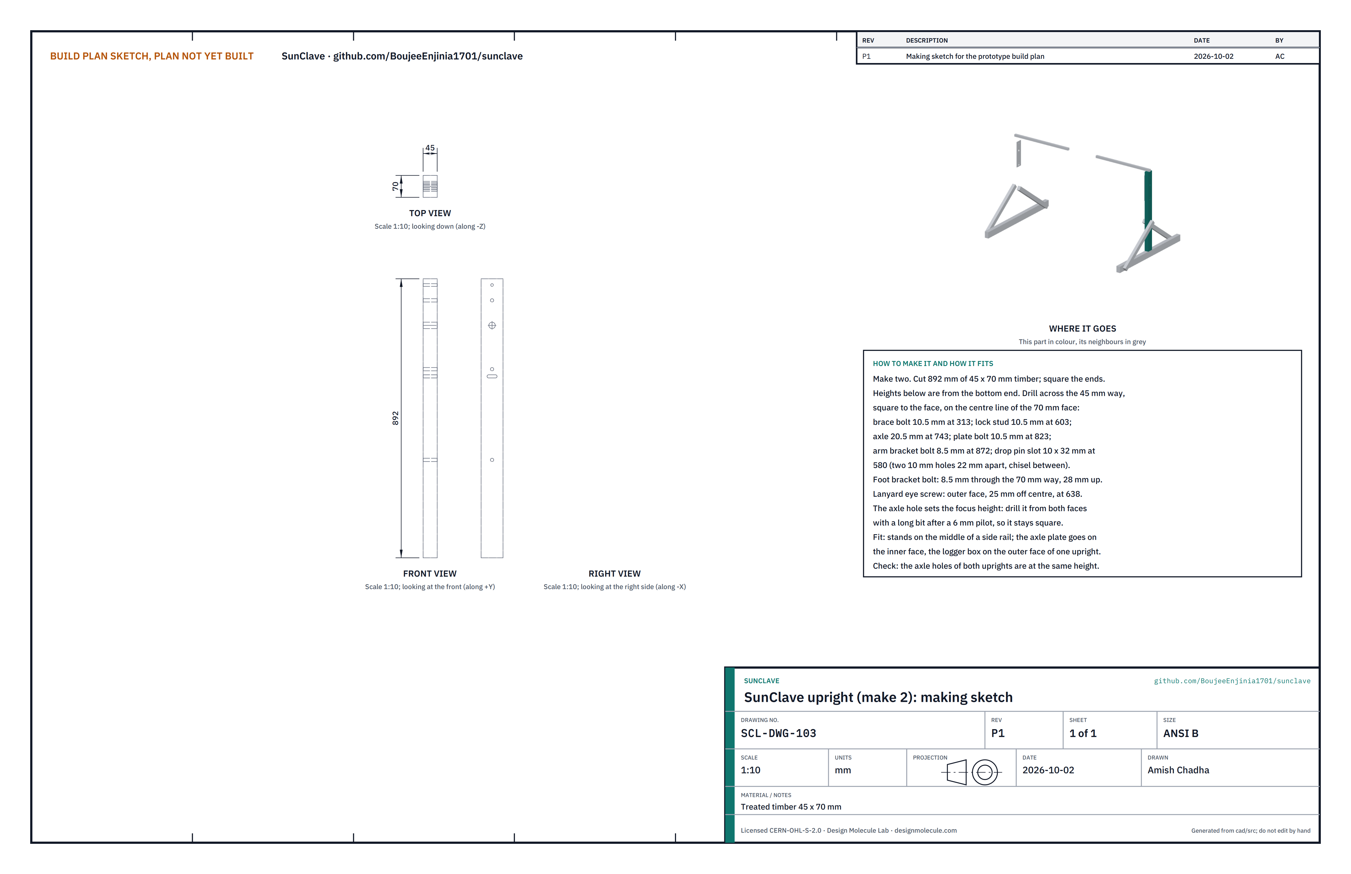
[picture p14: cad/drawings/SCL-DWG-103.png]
Figure 5. Making sketch of the upright


*Figure 5. Upright making sketch (SCL-DWG-103).*

**What it is and what it is made from.** The two posts that carry the axles, the tilt locks, the holder arms and, on the right, the logger box. Treated timber 45 x 70 mm, standing with the 45 mm face toward the dish.

**How to make it.**

1. Cut 892 mm and square both ends. Choose straight timber with no knots near the holes.
2. Mark a centre line on one 70 mm face. Measure every height from the bottom end.
3. Drill across the 45 mm way, square to the face, on the centre line: brace bolt 10.5 mm at 313; lock stud 10.5 mm at 603; axle 20.5 mm at 743; axle plate bolt 10.5 mm at 823; arm bracket bolt 8.5 mm at 872.
4. Drill the axle hole with a 6 mm pilot first, from both faces, then open it to 20.5 mm from both faces so it stays square.
5. Foot bracket bolt: 8.5 mm through the 70 mm way, 28 mm up from the bottom.
6. Drop pin slot: 10 mm high and 32 mm long across the 70 mm face, centred on the centre line at 580. Drill two 10 mm holes 22 mm apart, then chisel out between them.
7. Screw a small eye screw into the outer face 25 mm to one side of the centre line at 638, for the drop pin's lanyard.

**How it fits the parts next to it.**

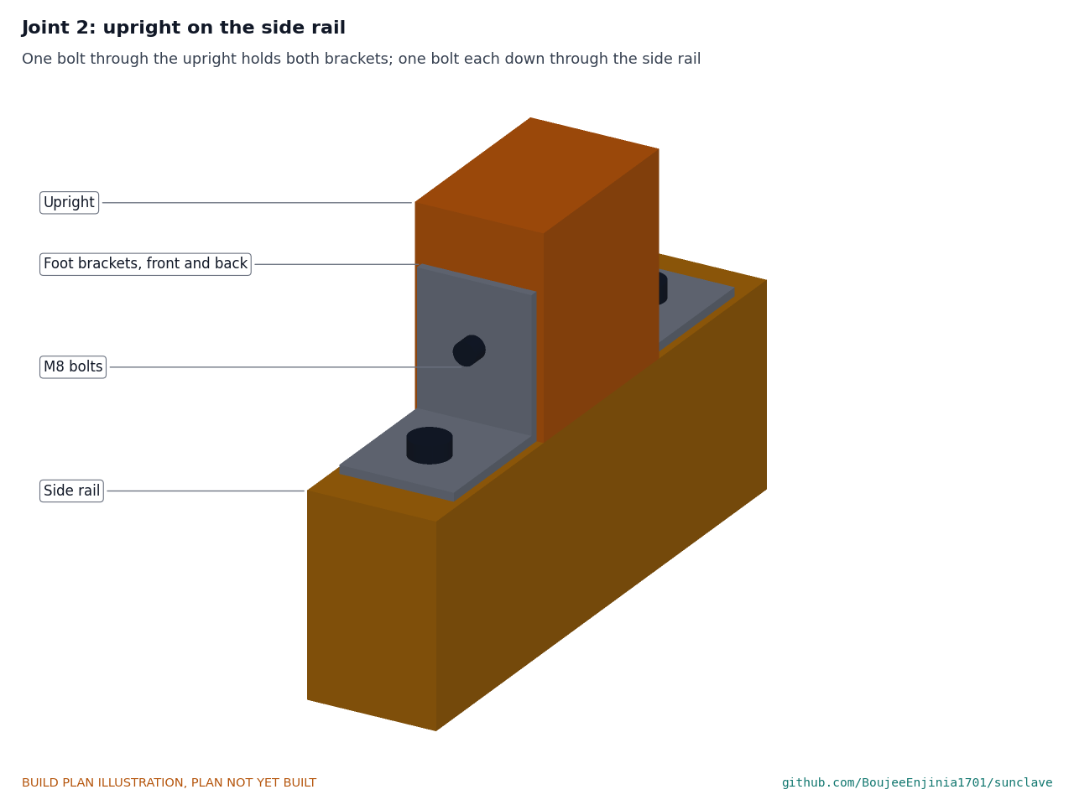
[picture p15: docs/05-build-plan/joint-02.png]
Figure 6. Joint 2: upright on the side rail


*Figure 6. Two angle brackets, front and back, hold the upright on the side rail; one bolt through the upright holds both, one bolt each goes down through the side rail.*

The bottom end stands on the middle of the side rail. The axle plate goes on its inner face, the holder arm on its top, and on the right upright the logger box on its outer face.

**Check before moving on.** Laid side by side, the axle holes of both uprights are at the same height within 1 mm.

### 3.4 Braces (make 4)

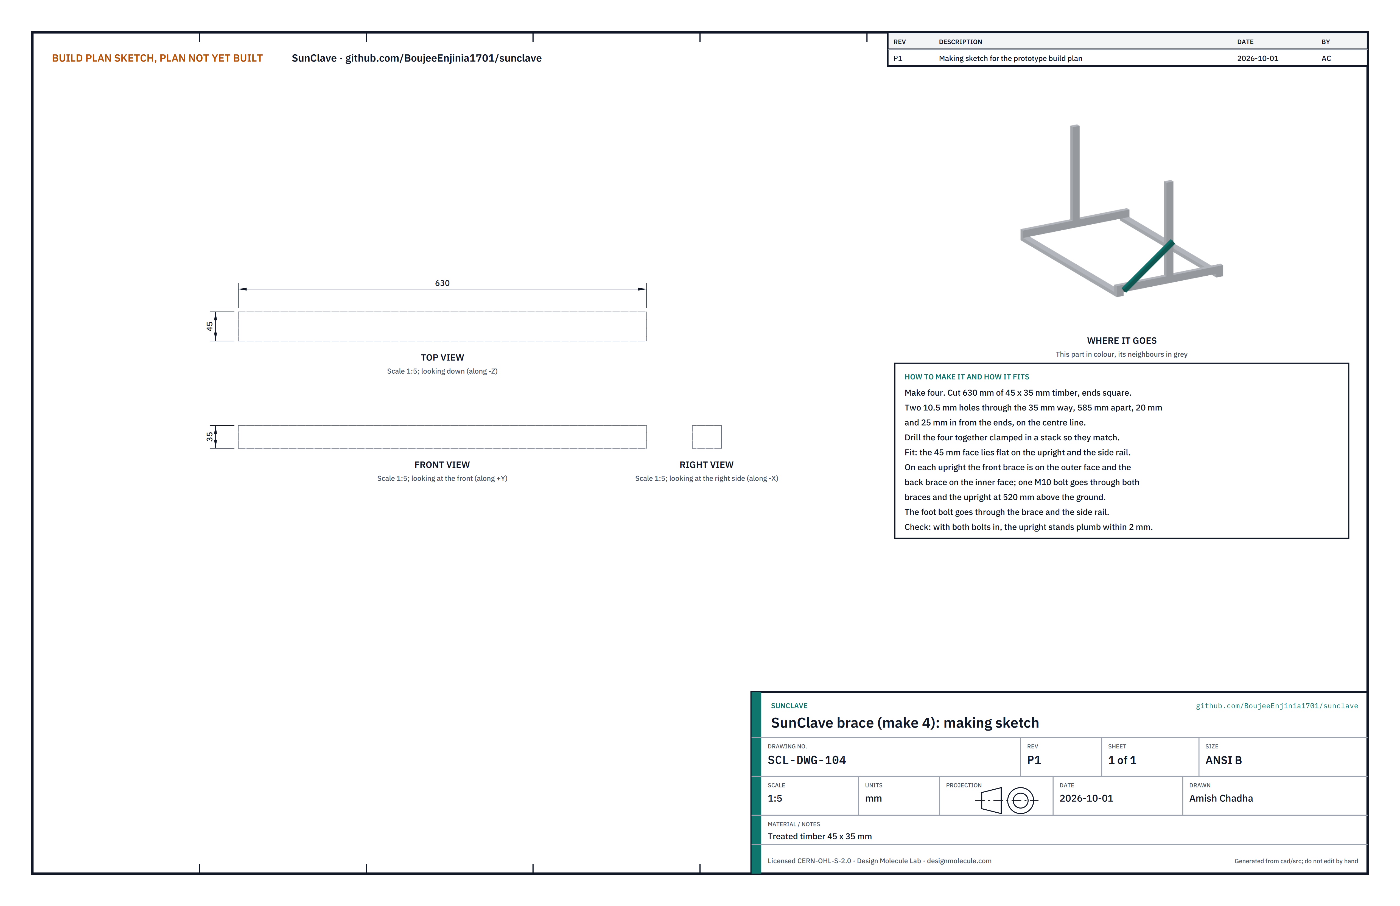
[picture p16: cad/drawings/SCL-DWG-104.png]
Figure 7. Making sketch of the brace


*Figure 7. Brace making sketch (SCL-DWG-104), drawn laid flat.*

**What it is and what it is made from.** The diagonals that keep each upright plumb, front and back. Treated timber 45 x 35 mm.

**How to make it.**

1. Cut four 630 mm lengths with square ends.
2. Drill two 10.5 mm holes through the 35 mm way on the centre line, 585 mm apart: one 20 mm from one end (the foot), one 25 mm from the other (the top). Drill the four clamped in a stack.

**How it fits the parts next to it.**

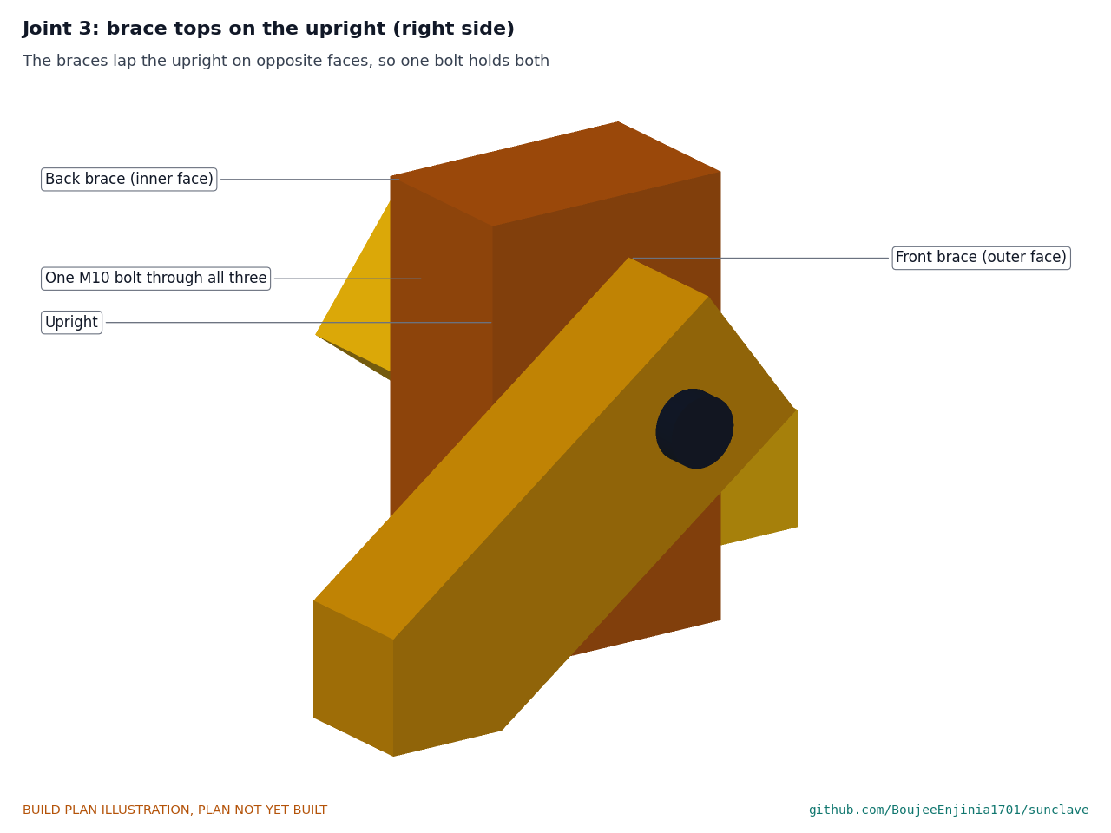
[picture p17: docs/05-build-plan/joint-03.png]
Figure 8. Joint 3: brace tops on the upright


*Figure 8. The front brace lies on the upright's outer face and the back brace on its inner face; one M10 bolt goes through both braces and the upright.*

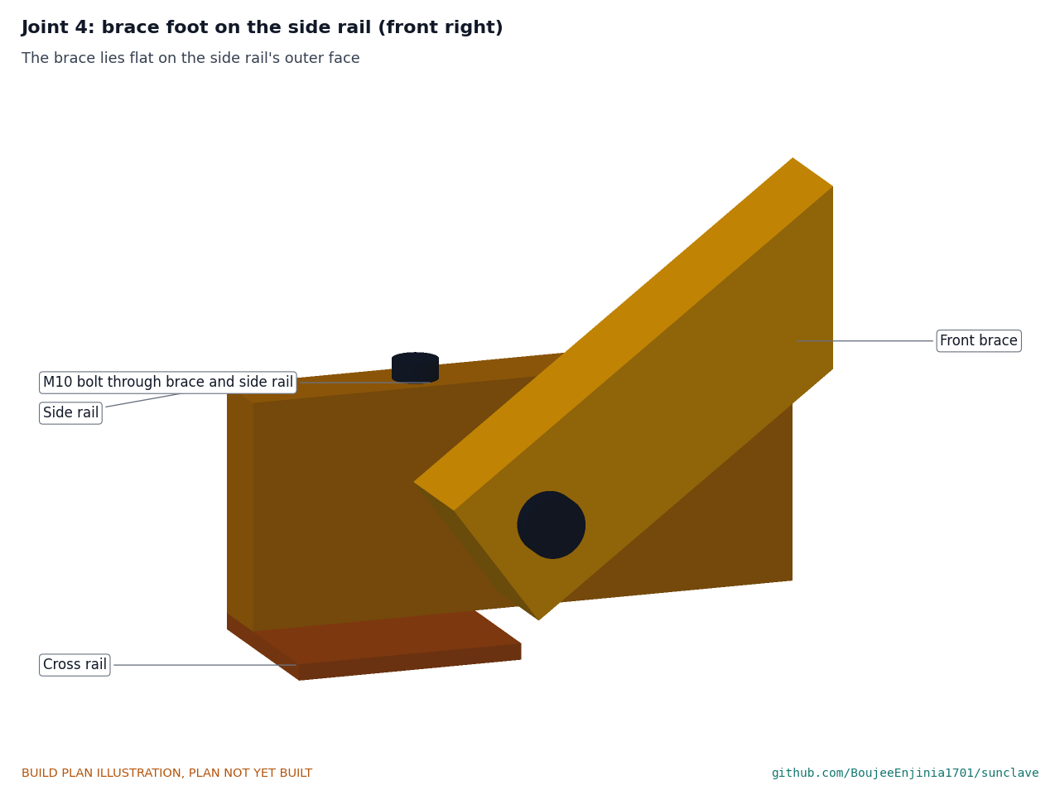
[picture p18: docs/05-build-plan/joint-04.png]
Figure 9. Joint 4: brace foot on the side rail


*Figure 9. Each brace foot lies flat on the side rail, 470 mm from the middle, held by one M10 bolt.*

The 45 mm face of each brace lies flat on the upright and on the side rail. The top bolt is 520 mm above the ground.

**Check before moving on.** With all bolts in, each upright stands plumb within 2 mm, checked with a spirit level on two faces.

### 3.5 Axle plates (make 2)

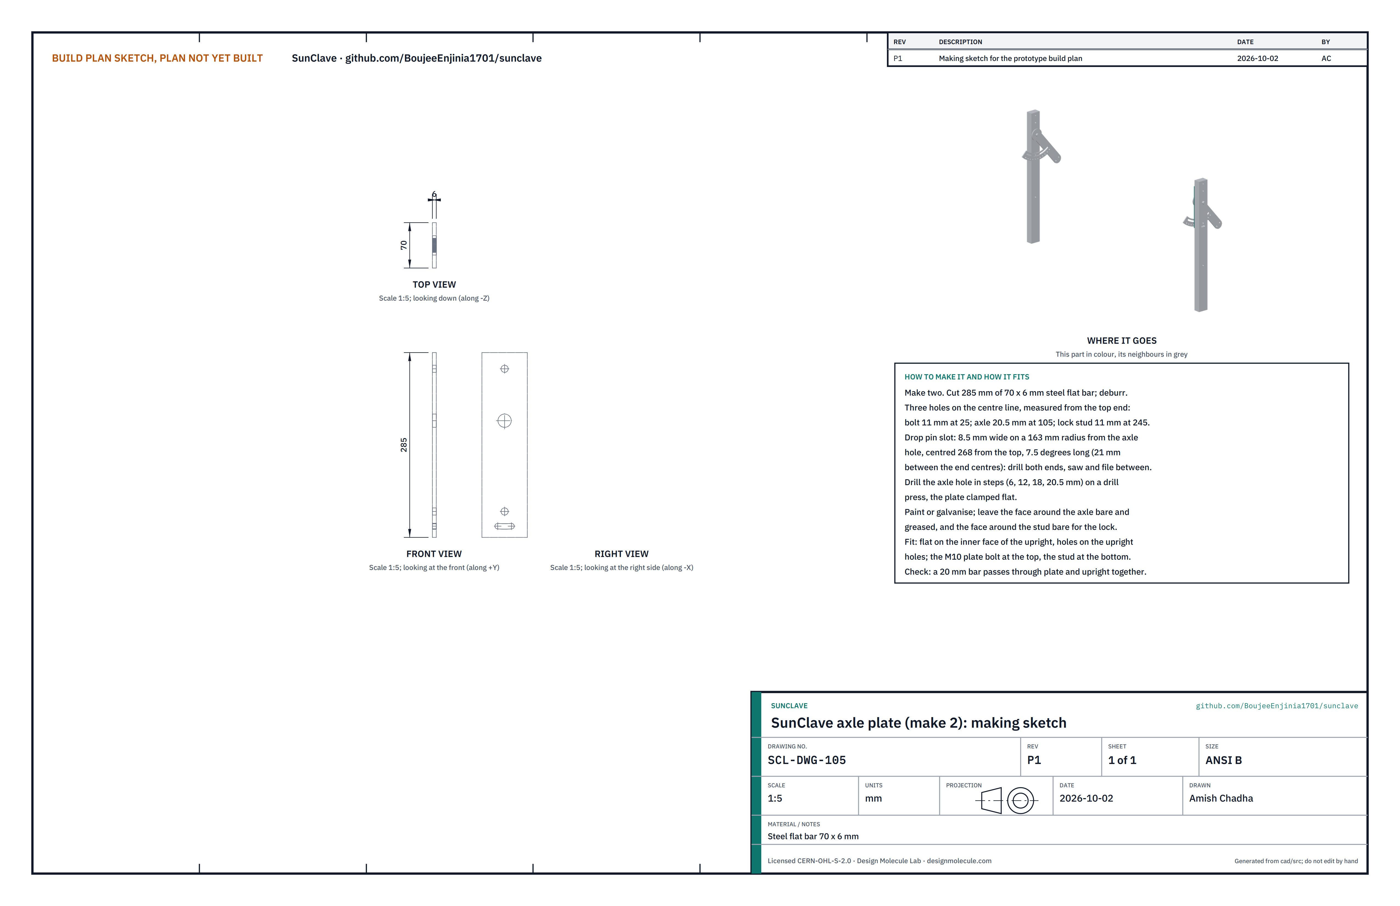
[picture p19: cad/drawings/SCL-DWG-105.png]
Figure 10. Making sketch of the axle plate


*Figure 10. Axle plate making sketch (SCL-DWG-105).*

**What it is and what it is made from.** A steel plate on the inner face of each upright that the yoke plate runs against and the lock clamps onto. Steel flat bar 70 x 6 mm.

**How to make it.**

1. Cut 285 mm and deburr.
2. On the centre line, measured from the top end: 11 mm hole at 25 (plate bolt), 20.5 mm hole at 105 (axle), 11 mm hole at 245 (lock stud). Drill the axle hole in steps (6, 12, 18, 20.5 mm) with the plate clamped flat.
3. Drop pin slot: 8.5 mm wide, curved on a 163 mm radius about the axle hole, centred 268 from the top and 21 mm long between its end centres (7.5 degrees). Drill 8.5 mm at both ends, saw between and file smooth.
4. Paint the plate, but leave the inner face bare where the yoke plate and the lock spacer run, and grease it there.

**How it fits the parts next to it.** It lies flat on the upright's inner face with its holes on the upright's holes, the top of the plate 44 mm below the top of the upright. An M10 bolt at the top holds it, with the nut on the inside; the axle and the lock stud pass through the other two holes, and the drop pin through the slot (Figures 27 and 28).

**Check before moving on.** A 20 mm bar passes through the plate and the upright together, and an 8 mm bar slides the full length of the plate's slot through the slot in the upright.

### 3.6 Axles (make 2)

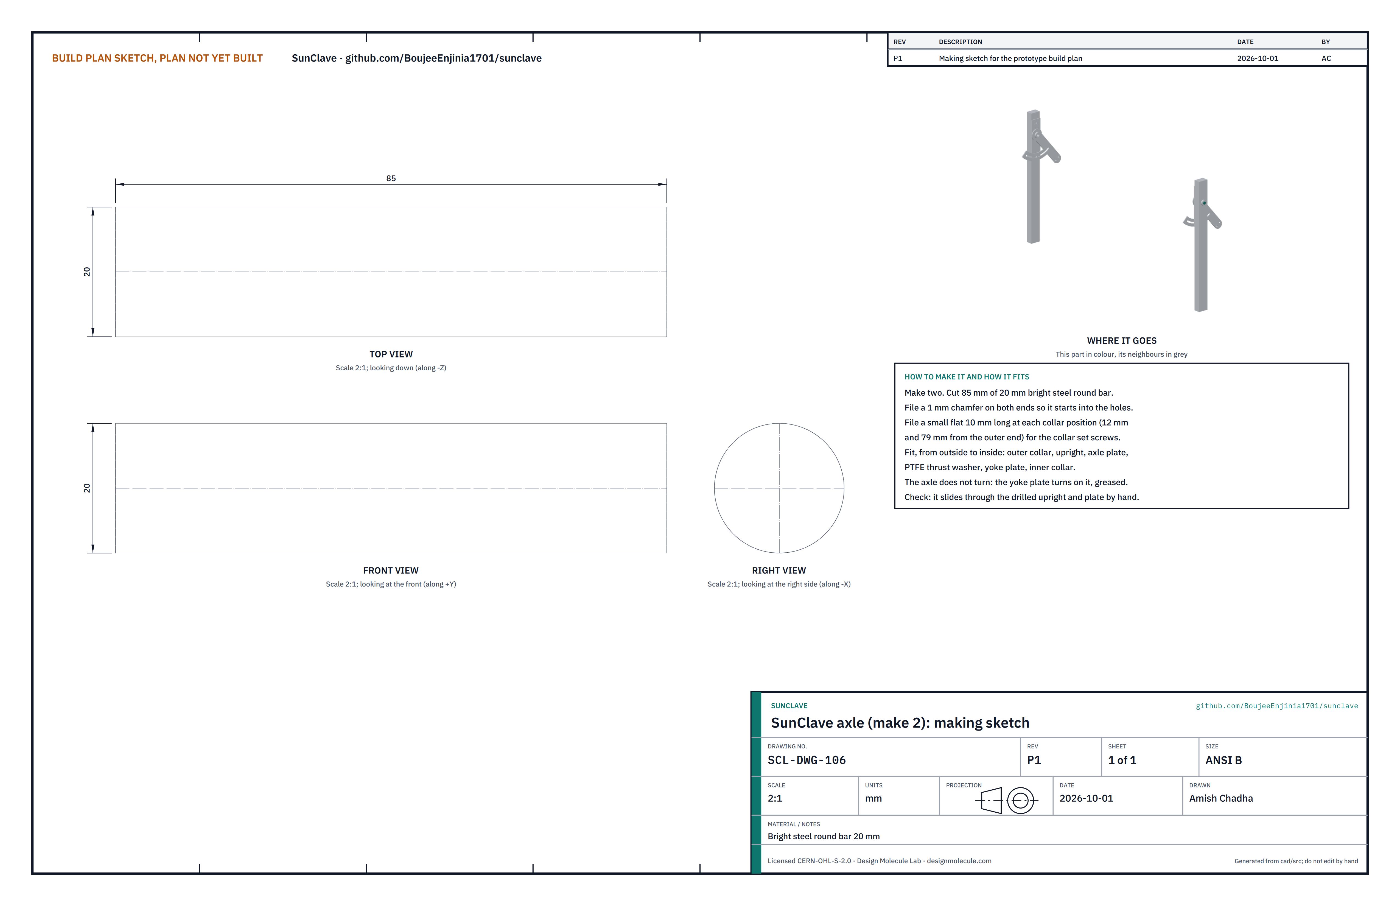
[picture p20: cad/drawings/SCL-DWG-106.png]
Figure 11. Making sketch of the axle


*Figure 11. Axle making sketch (SCL-DWG-106).*

**What it is and what it is made from.** The fixed pin each yoke plate turns on. Bright steel round bar 20 mm.

**How to make it.**

1. Cut 85 mm and file a 1 mm chamfer on both ends.
2. File a small flat 10 mm long at each collar position, 8 mm and 79 mm from the outer end, for the collar set screws.

**How it fits the parts next to it.** From outside to inside: outer collar, upright, axle plate, PTFE thrust washer, yoke plate, inner collar. The axle does not turn; the yoke plate turns on it.

**Check before moving on.** It slides through the drilled upright and axle plate by hand, and the yoke plate turns on it freely.

### 3.7 Ribs (make 12)

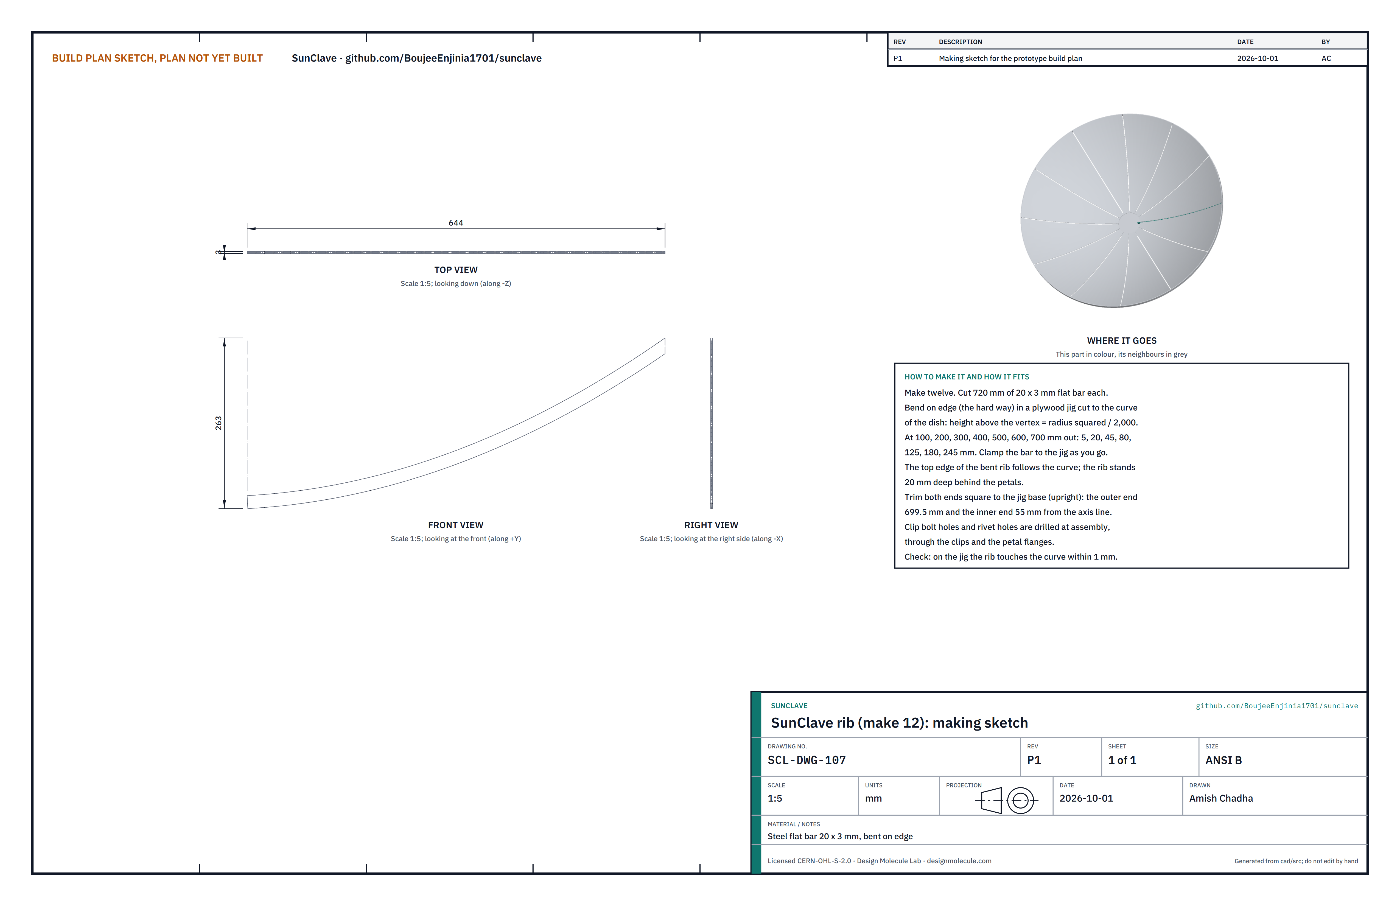
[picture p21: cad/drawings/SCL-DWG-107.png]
Figure 12. Making sketch of the rib


*Figure 12. Rib making sketch (SCL-DWG-107), drawn in the plane it lies in.*

**What it is and what it is made from.** The twelve curved bars behind the petals that give the dish its shape. Steel flat bar 20 x 3 mm, bent on edge.

**How to make it.**

1. Make a bending jig: a sheet of 18 mm plywood with the dish curve drawn on it from the axis line outward. The curve's height above the vertex is the radius squared divided by 2,000: at 100, 200, 300, 400, 500, 600 and 700 mm out it is 5, 20, 45, 80, 125, 180 and 245 mm. Screw hardwood blocks along the curve every 50 mm.
2. Cut twelve 720 mm lengths. Bend each on edge against the blocks a little at a time, with clamps following the bend; check against the curve. Bend one first and confirm it does not buckle.
3. With the rib on the jig, trim both ends square to the jig base: the outer end 699.5 mm and the inner end 55 mm from the axis line.
4. Clip bolt holes and rivet holes are drilled at assembly, through the clips and the flanges.

**How it fits the parts next to it.**

The rib stands on edge, 20 mm deep, just behind the petals, with its top edge along the dish curve. Its inner end stands on the hub plate (Figure 14), its outer end meets the inside of the rim band (Figure 18), and the petal flanges lie either side of it (Figure 17).

**Check before moving on.** On the jig, the rib touches the curve within 1 mm along its length, and all twelve match.

### 3.8 Hub plate

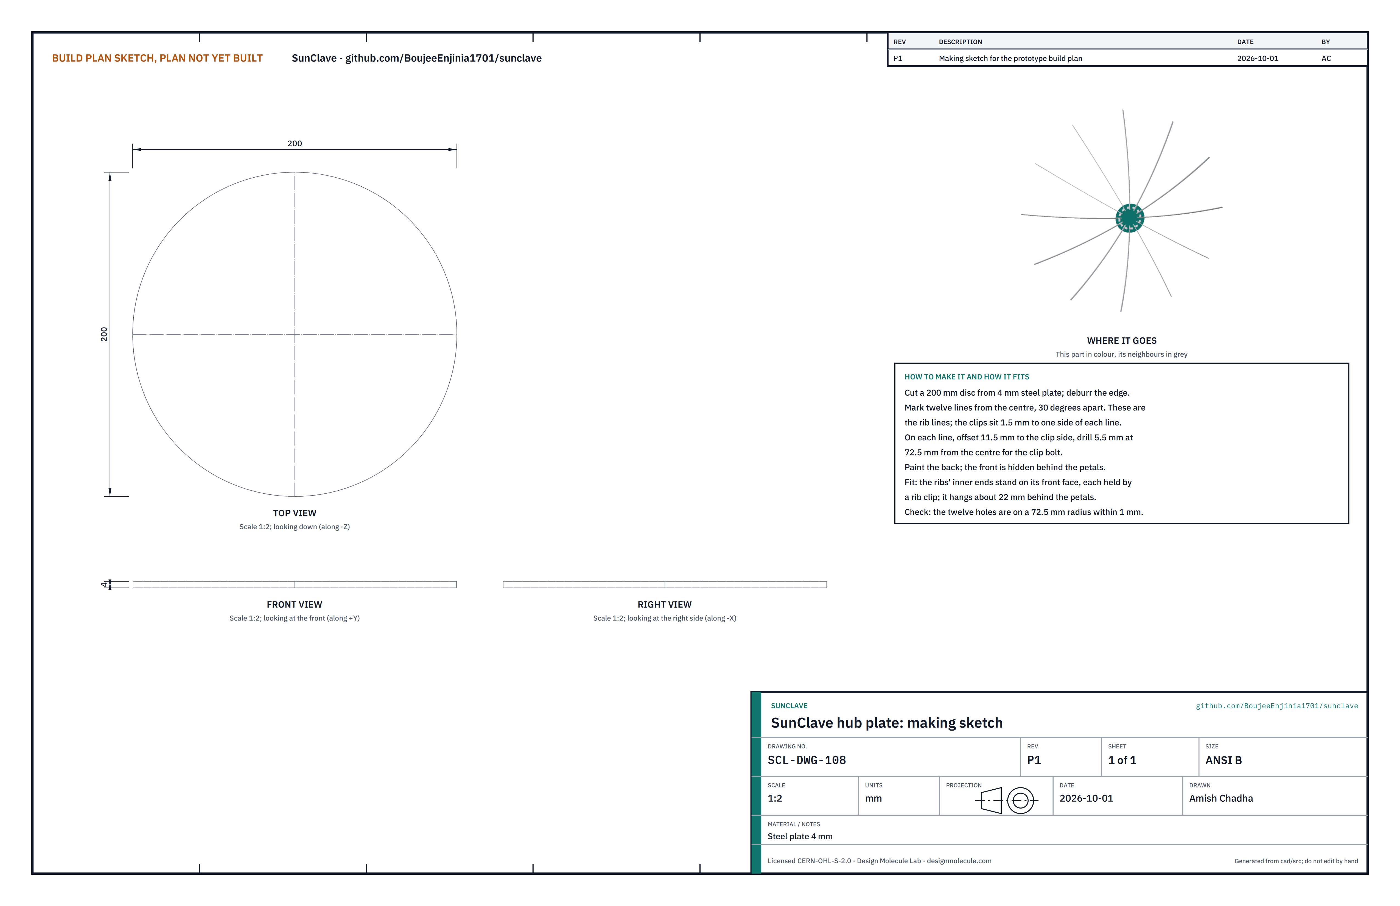
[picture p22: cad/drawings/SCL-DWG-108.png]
Figure 13. Making sketch of the hub plate


*Figure 13. Hub plate making sketch (SCL-DWG-108).*

**What it is and what it is made from.** The disc behind the centre of the dish that ties the inner ends of the ribs together. Steel plate 4 mm.

**How to make it.**

1. Cut a 200 mm disc and deburr the edge.
2. Mark twelve lines from the centre, 30 degrees apart; these are the rib lines.
3. On each line, offset 11.5 mm to the same side, drill 5.5 mm at 72.5 mm from the centre for a clip bolt.

**How it fits the parts next to it.**

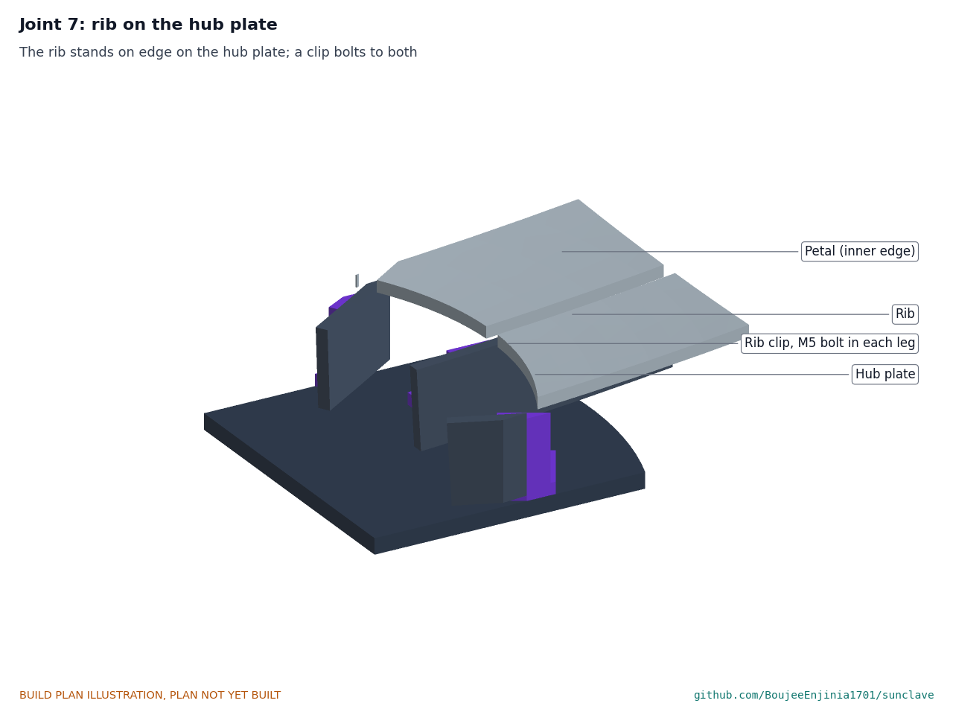
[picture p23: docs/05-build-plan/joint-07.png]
Figure 14. Joint 7: rib on the hub plate


*Figure 14. Each rib's inner end stands on the hub plate; a rib clip bolts to both.*

The ribs' inner ends stand on its front face, each beside one of the twelve lines, and a clip bolts each rib to it. It sits about 22 mm behind the petals.

**Check before moving on.** The twelve holes are on a 72.5 mm radius within 1 mm.

### 3.9 Rib clips (make 24)

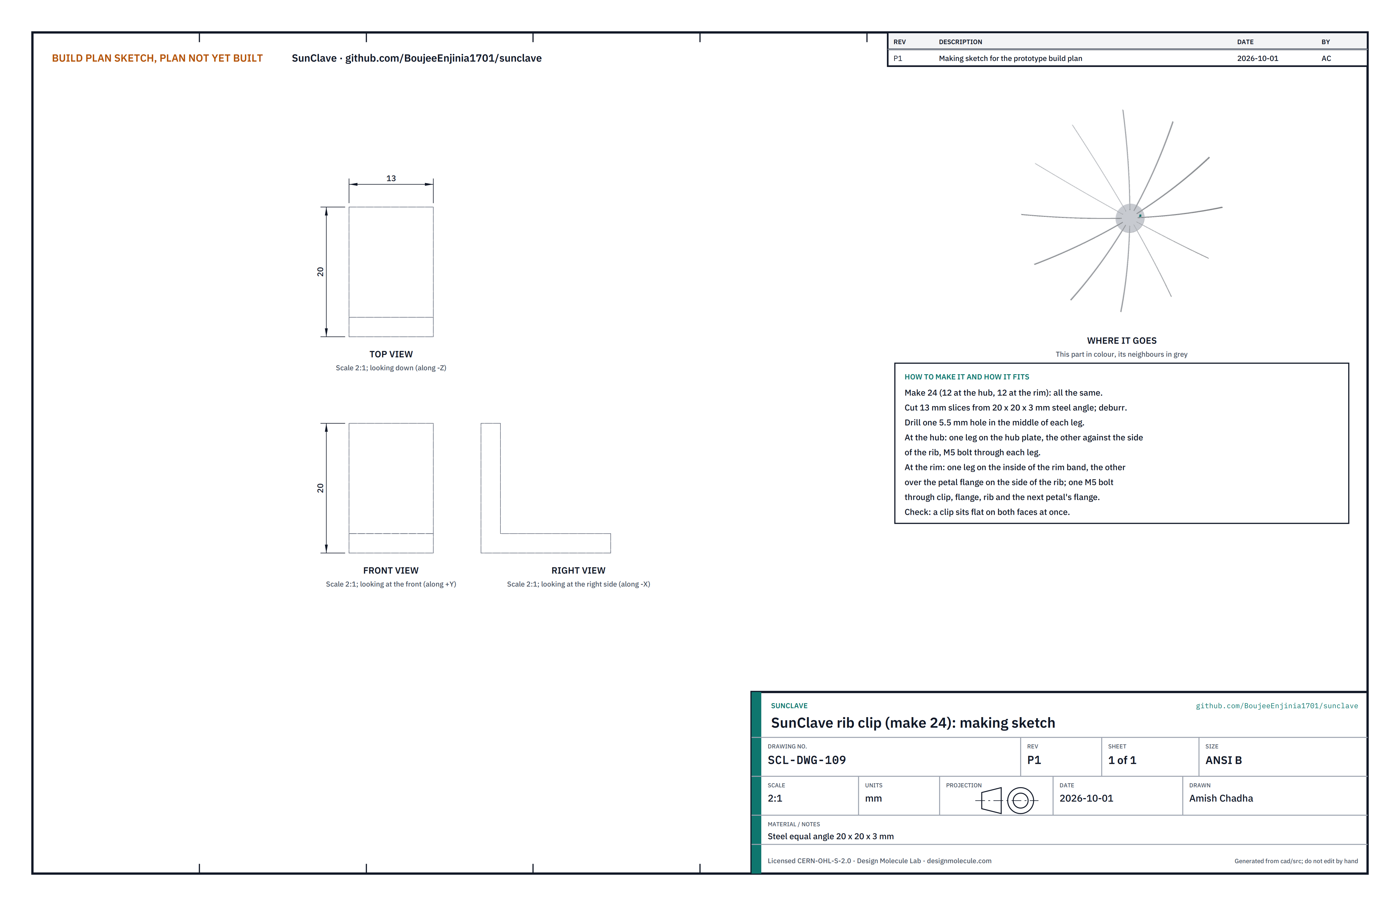
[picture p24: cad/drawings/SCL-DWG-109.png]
Figure 15. Making sketch of the rib clip


*Figure 15. Rib clip making sketch (SCL-DWG-109).*

**What it is and what it is made from.** Small angles that join each end of each rib to the hub plate or the rim band. Steel equal angle 20 x 20 x 3 mm.

**How to make it.**

1. Cut 24 slices 13 mm long and deburr.
2. Drill one 5.5 mm hole in the middle of each leg.

**How it fits the parts next to it.** At the hub, one leg lies on the hub plate and the other against the side of the rib (Figure 14). At the rim, one leg lies on the inside of the rim band and the other over the petal flange on the side of the rib, and one M5 bolt goes through the clip, both petal flanges and the rib (Figure 18).

**Check before moving on.** Each clip sits flat on both faces at once.

### 3.10 Rim band

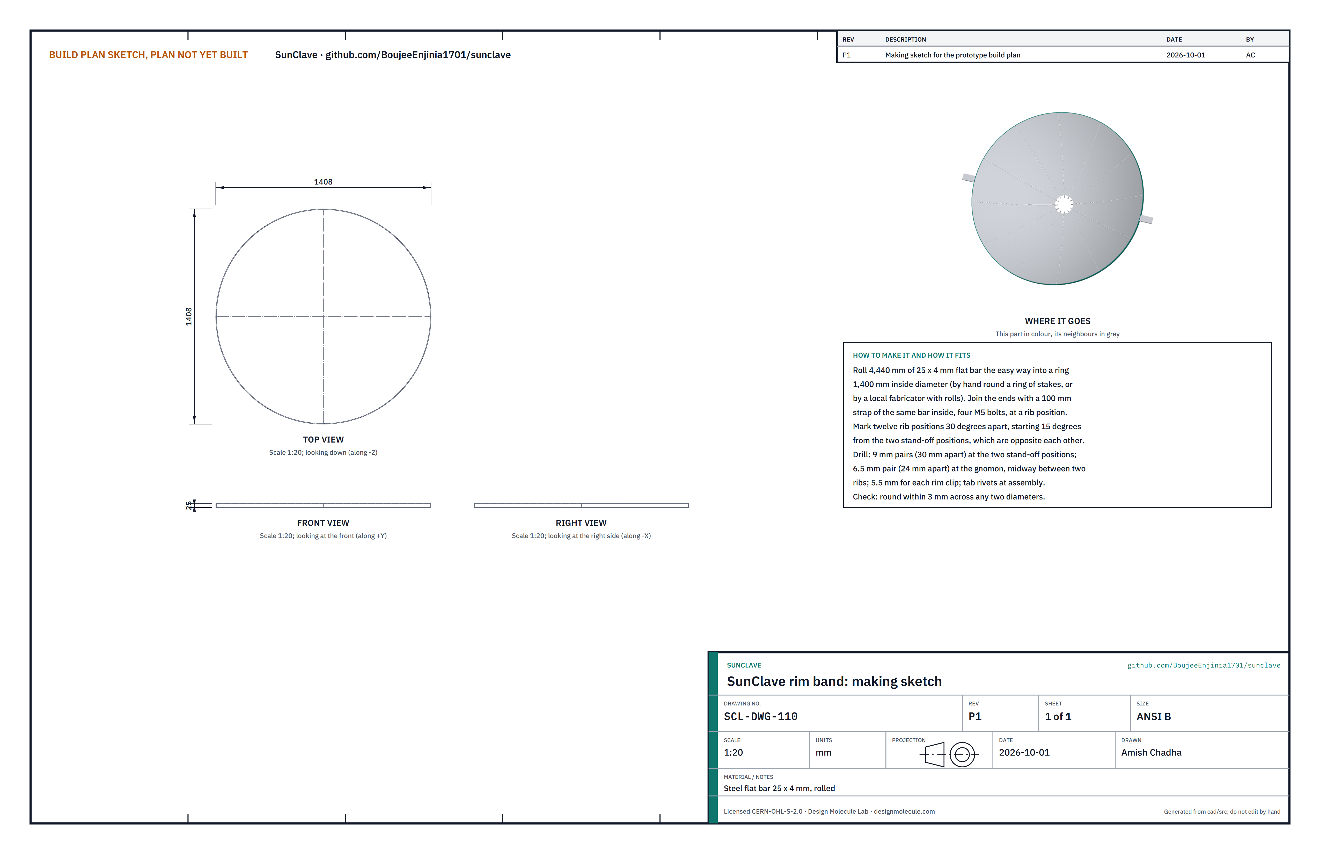
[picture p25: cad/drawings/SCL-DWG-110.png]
Figure 16. Making sketch of the rim band


*Figure 16. Rim band making sketch (SCL-DWG-110).*

**What it is and what it is made from.** The steel hoop round the edge of the dish that ties the rib ends together and carries the gnomon and the two stand-offs. Steel flat bar 25 x 4 mm, rolled.

**How to make it.**

1. Roll 4,440 mm of bar the easy way into a hoop of 1,400 mm inside diameter, by hand round a circle of stakes in the ground, or have a local fabricator roll it.
2. Join the ends with a 100 mm strap of the same bar on the inside, four M5 bolts, placed where a rib will be.
3. Mark the two stand-off positions opposite each other, then the twelve rib positions 30 degrees apart starting 15 degrees from a stand-off position, then the gnomon position midway between two ribs, 90 degrees from both stand-offs.
4. Drill: two 9 mm holes 30 mm apart at each stand-off position; two 6.5 mm holes 24 mm apart at the gnomon; one 5.5 mm hole 6.5 mm up from the bottom edge, 12.5 mm beside each rib position, for its clip. Tab rivet holes are drilled at assembly.

**How it fits the parts next to it.**

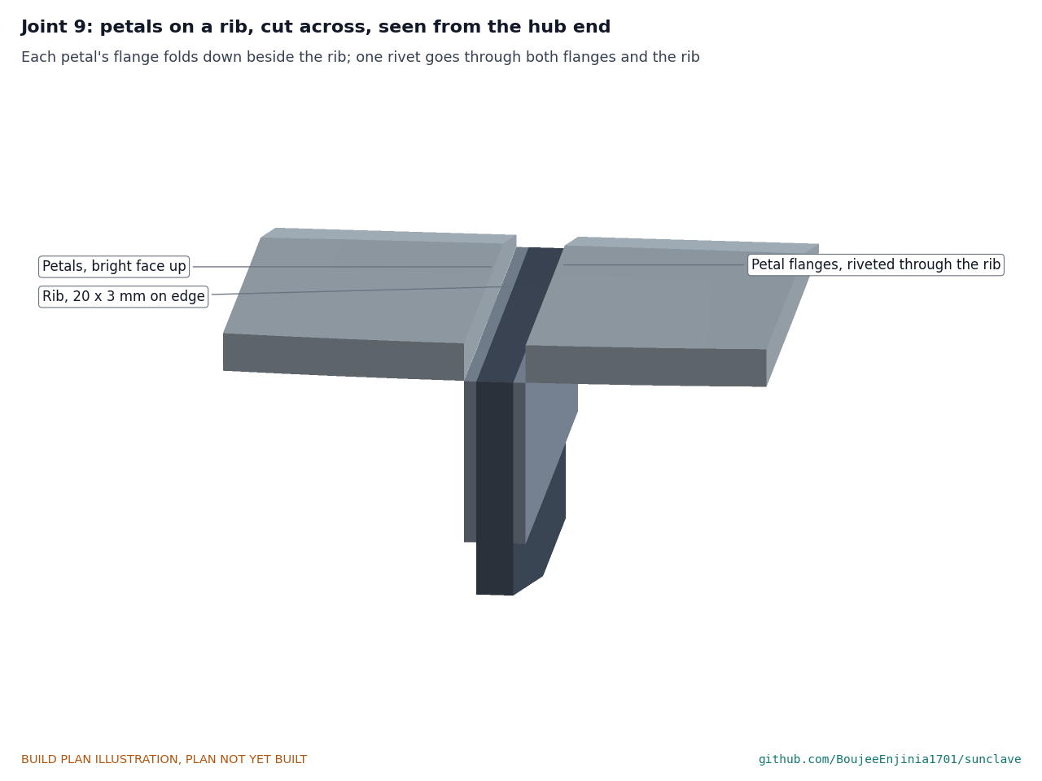
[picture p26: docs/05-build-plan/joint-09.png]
Figure 17. Joint 9: petals on a rib, cut across


*Figure 17. Each petal's flange folds down beside the rib, and one rivet goes through both flanges and the rib.*

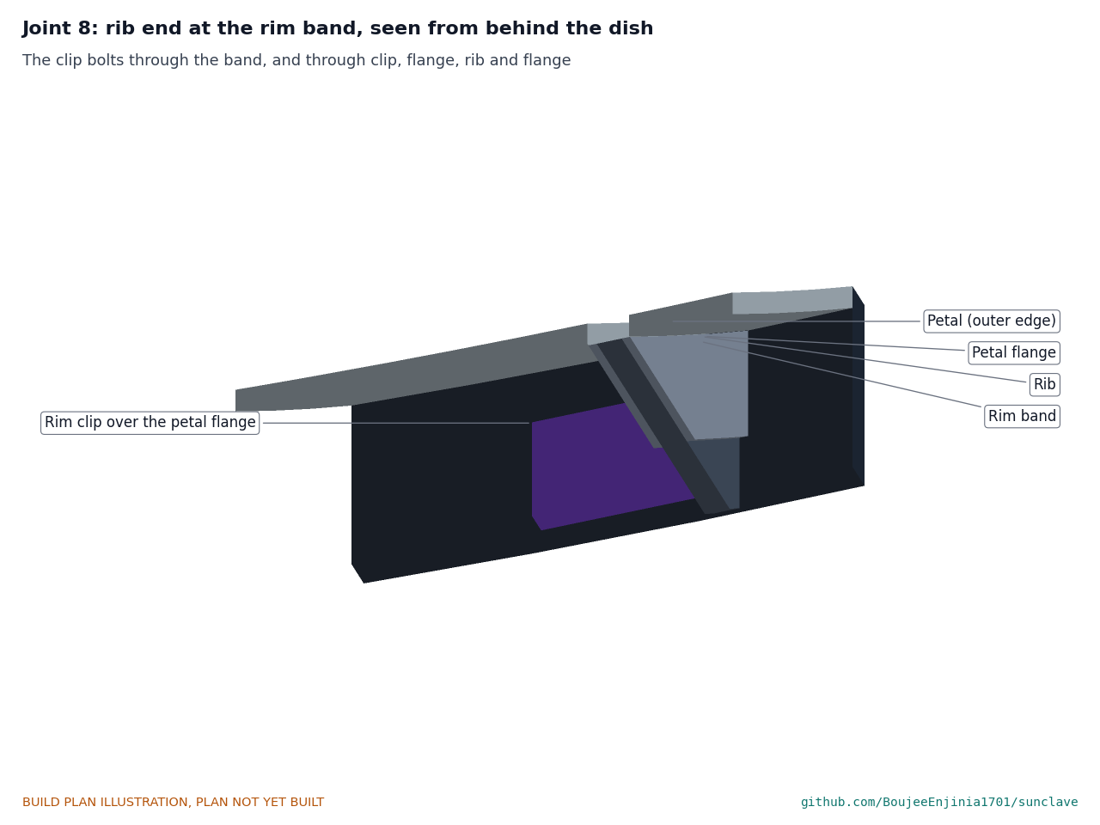
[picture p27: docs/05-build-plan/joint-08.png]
Figure 18. Joint 8: rib end at the rim band


*Figure 18. Seen from behind the dish: the rim clip bolts to the band and, over the petal flange, to the rib.*

The band stands round the rib ends with its top edge level with the edge of the petals. The rib ends stop 0.5 mm inside it and are held by the rim clips; the petal tabs are riveted to its inside face.

**Check before moving on.** Round within 3 mm across any two diameters, and flat (not twisted) when laid on the floor.

### 3.11 Petals (make 12)

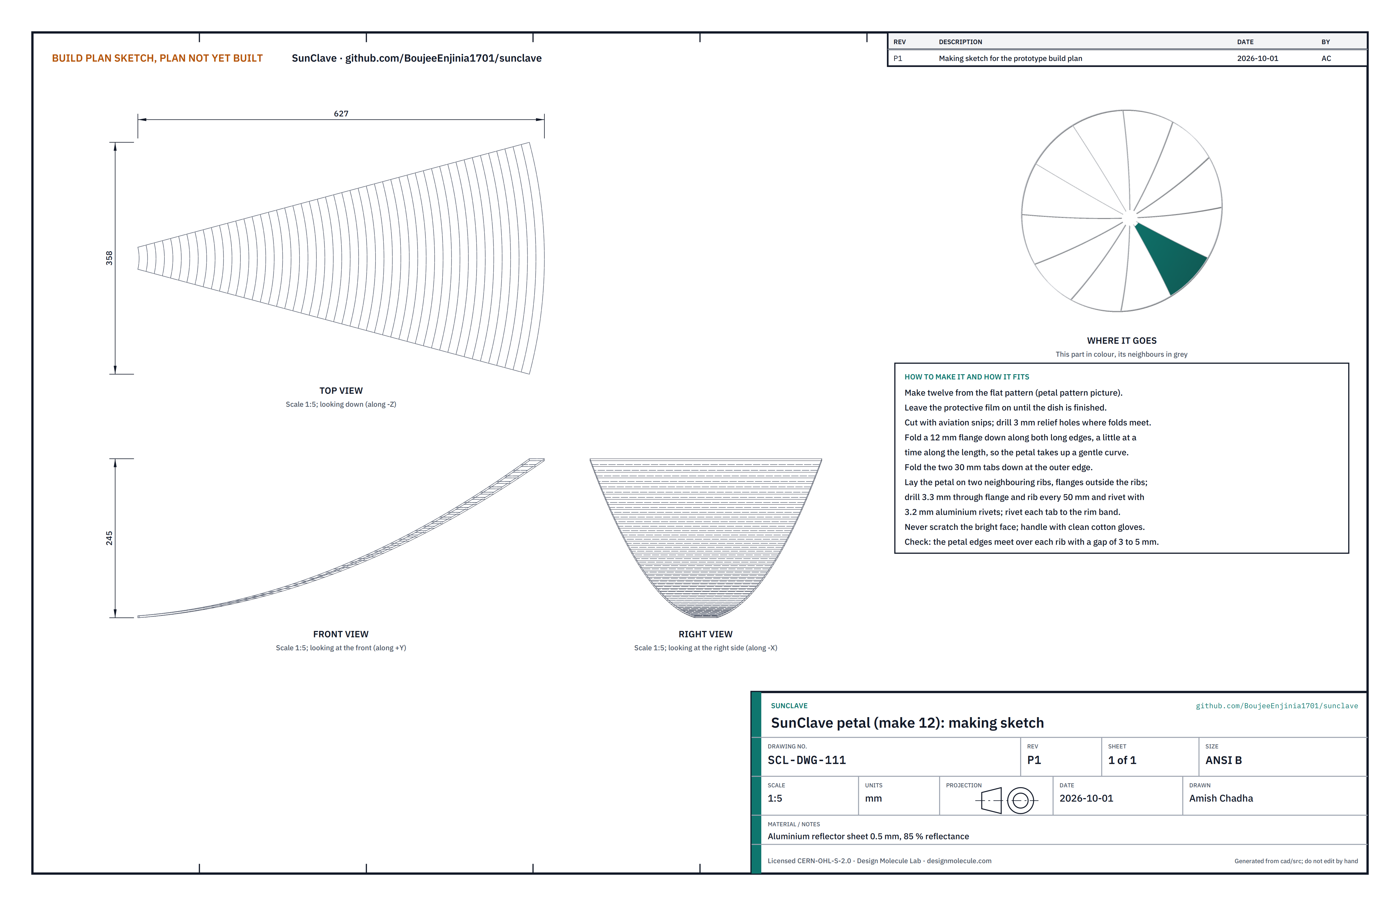
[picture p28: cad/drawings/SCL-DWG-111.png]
Figure 19. Making sketch of the petal


*Figure 19. Petal making sketch (SCL-DWG-111).*

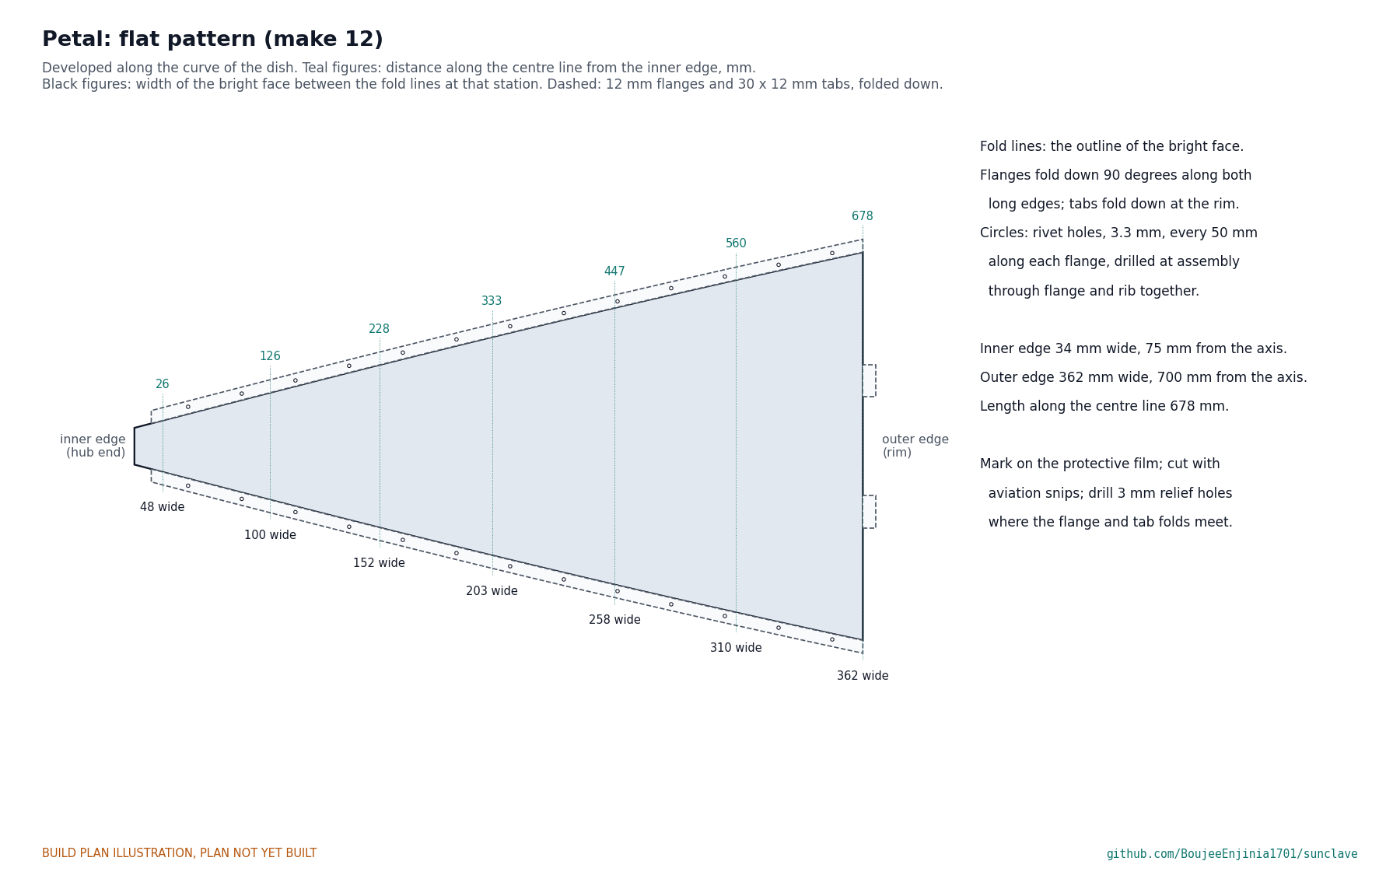
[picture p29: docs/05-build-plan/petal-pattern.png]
Figure 20. Flat pattern of the petal


*Figure 20. Flat pattern of one petal, with the fold lines, flanges, tabs and rivet positions.*

**What it is and what it is made from.** The twelve mirror segments that make up the dish. Polished or anodised aluminium reflector sheet 0.5 mm, reflectance 85 % or more, with its protective film on.

**How to make it.**

1. Make a template of the flat pattern (Figure 20) from thin card or hardboard: 34 mm wide at the inner edge, 362 mm wide at the outer edge, 678 mm long along the centre line, with a 12 mm flange beyond each long edge and two 30 x 12 mm tabs beyond the outer edge.
2. Mark twelve petals on the film side and cut them with aviation snips. Drill 3 mm relief holes where the flange and tab folds meet.
3. Fold the flanges down 90 degrees along both long edges with a hand seamer, a little at a time along the length, so the petal takes up a gentle curve. Fold the two tabs down.
4. Keep the bright face covered and handle the petals with clean cotton gloves.

**How it fits the parts next to it.** Each petal lies across two neighbouring ribs, its flanges outside the ribs. Rivets go every 50 mm through a flange, the rib and the next petal's flange (Figure 17). The tabs are riveted inside the rim band. Neighbouring petals meet over each rib with a 3 to 5 mm gap.

**Check before moving on.** The flanges are square to the face along their length, and the bright face has no creases or scratches.

### 3.12 Gnomon on its bracket

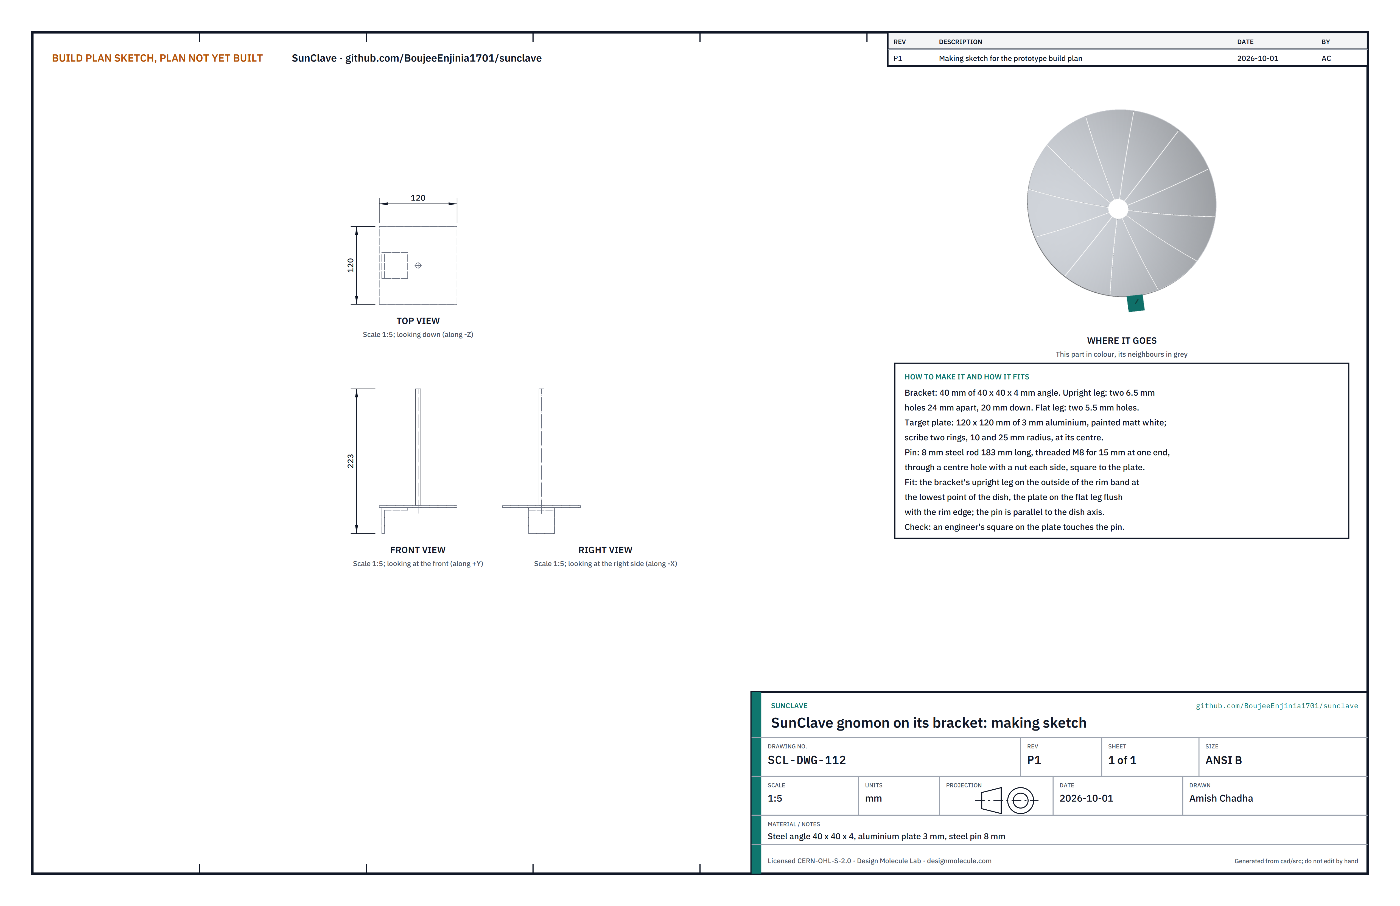
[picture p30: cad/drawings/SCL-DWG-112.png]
Figure 21. Making sketch of the gnomon


*Figure 21. Gnomon making sketch (SCL-DWG-112).*

**What it is and what it is made from.** The aiming sight: a pin whose shadow falls on a target when the dish faces the sun. A 40 mm length of 40 x 40 x 4 mm steel angle, a 120 x 120 mm plate of 3 mm aluminium, and 8 mm steel rod.

**How to make it.**

1. Bracket: drill two 6.5 mm holes 24 mm apart, 20 mm down, in the upright leg; two 5.5 mm holes in the flat leg.
2. Target plate: paint it matt white; scribe two rings, 10 and 25 mm radius, round its centre; drill an 8.5 mm centre hole and two 5.5 mm holes to match the bracket.
3. Pin: 183 mm of 8 mm rod, threaded M8 for 15 mm at one end; fit it through the centre hole with a nut each side, square to the plate.

**How it fits the parts next to it.**

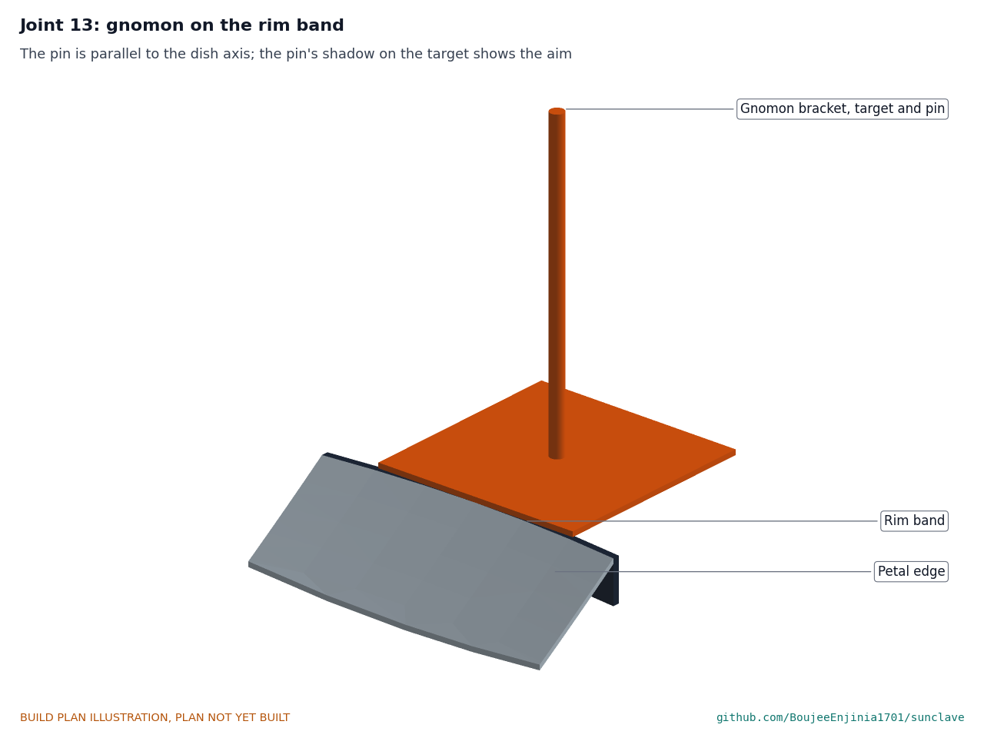
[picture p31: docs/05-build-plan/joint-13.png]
Figure 22. Joint 13: gnomon on the rim band


*Figure 22. The bracket bolts to the outside of the rim band; the plate sits on its flat leg, level with the rim edge; the pin is parallel to the dish axis.*

The bracket's upright leg bolts to the outside of the rim band at the gnomon position with two M6 bolts; the plate bolts to the flat leg with two M5 bolts, its inner edge on the top edge of the band.

**Check before moving on.** An engineer's square on the plate touches the pin along its length.

### 3.13 Rim stand-offs (make 2)

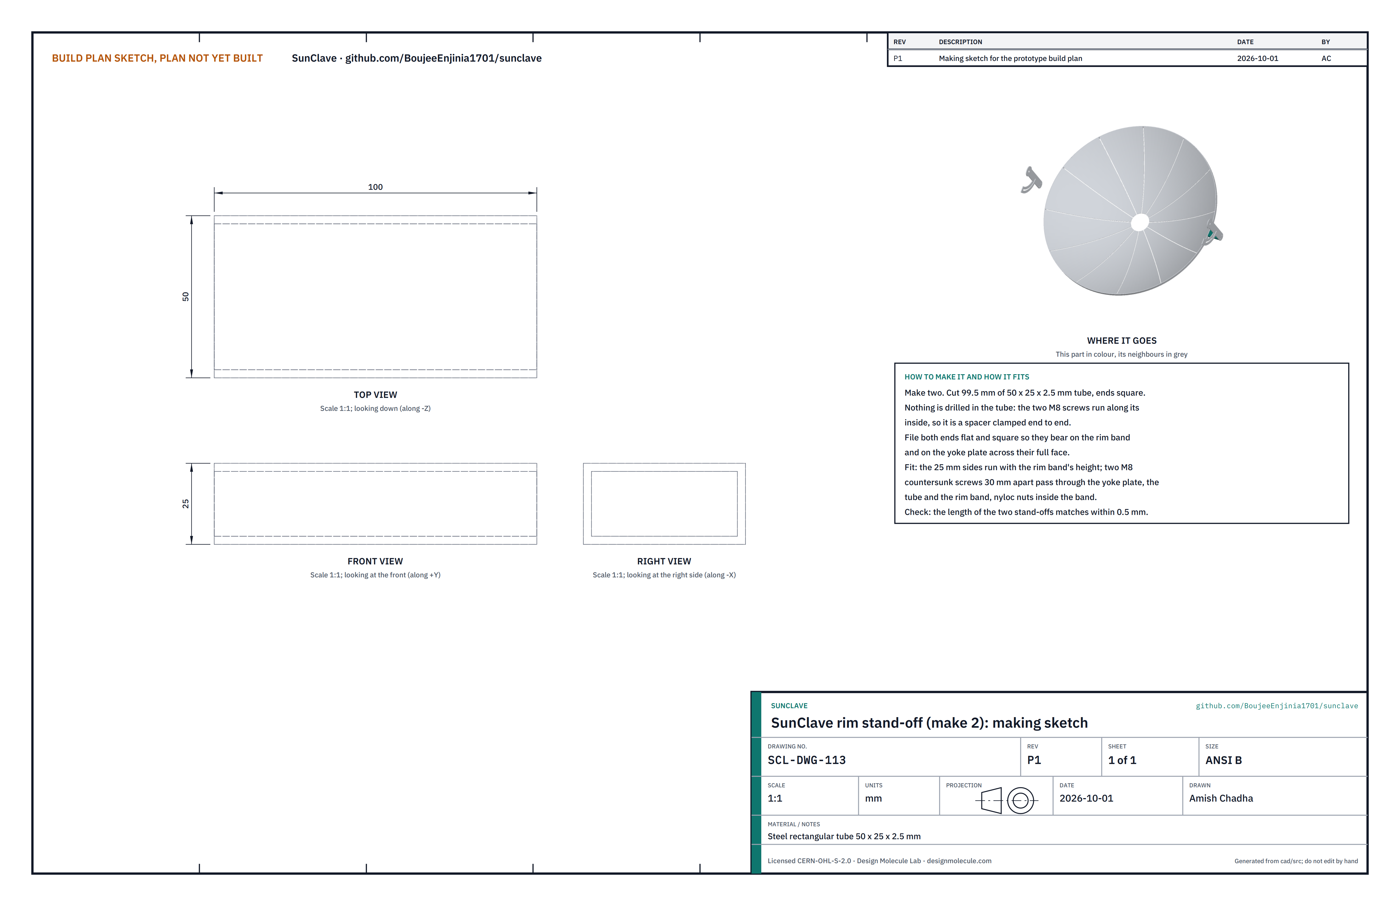
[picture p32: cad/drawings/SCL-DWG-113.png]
Figure 23. Making sketch of the rim stand-off


*Figure 23. Rim stand-off making sketch (SCL-DWG-113).*

**What it is and what it is made from.** A short tube on each side of the dish that spaces the rim band off the yoke plate. Steel rectangular tube 50 x 25 x 2.5 mm.

**How to make it.**

1. Cut 99.5 mm with both ends square, and file the ends flat.
2. Drill nothing: the two screws run along its inside.

**How it fits the parts next to it.**

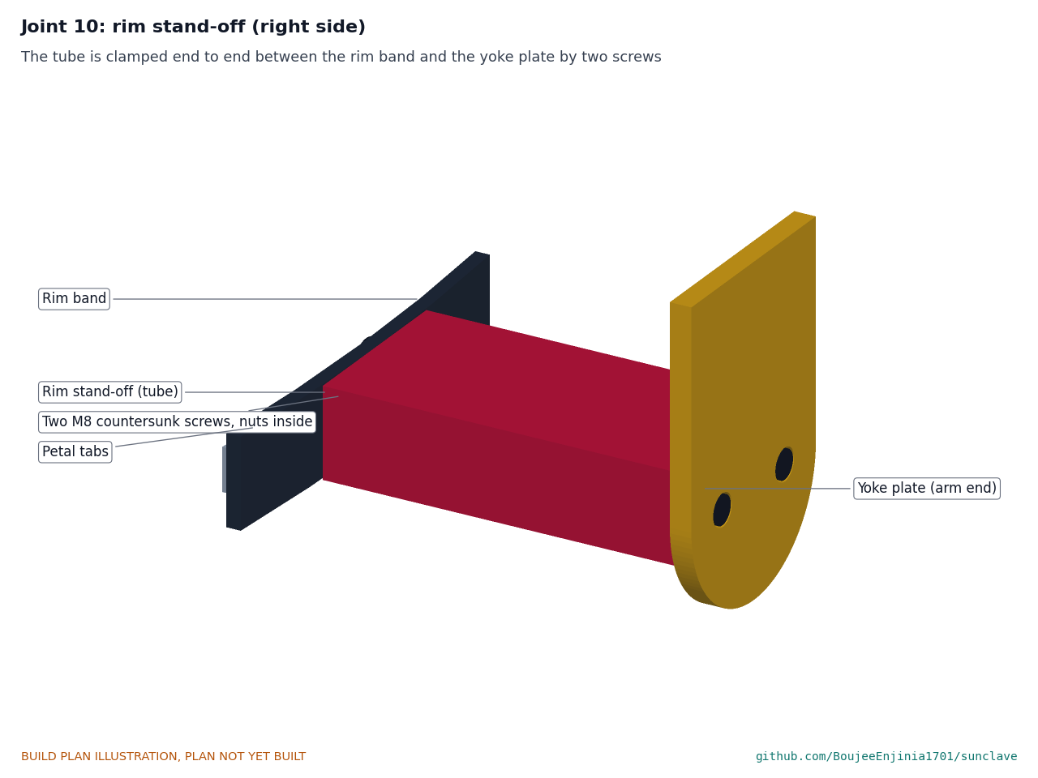
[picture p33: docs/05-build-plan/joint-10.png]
Figure 24. Joint 10: rim stand-off


*Figure 24. The tube is clamped end to end between the rim band and the yoke plate by two M8 countersunk screws, with nyloc nuts inside the band.*

The 25 mm sides run with the height of the rim band. One end bears on the outside of the band, the other on the inner face of the yoke plate's arm.

**Check before moving on.** The two stand-offs are the same length within 0.5 mm.

### 3.14 Yoke plates (make 2, a left and a right)

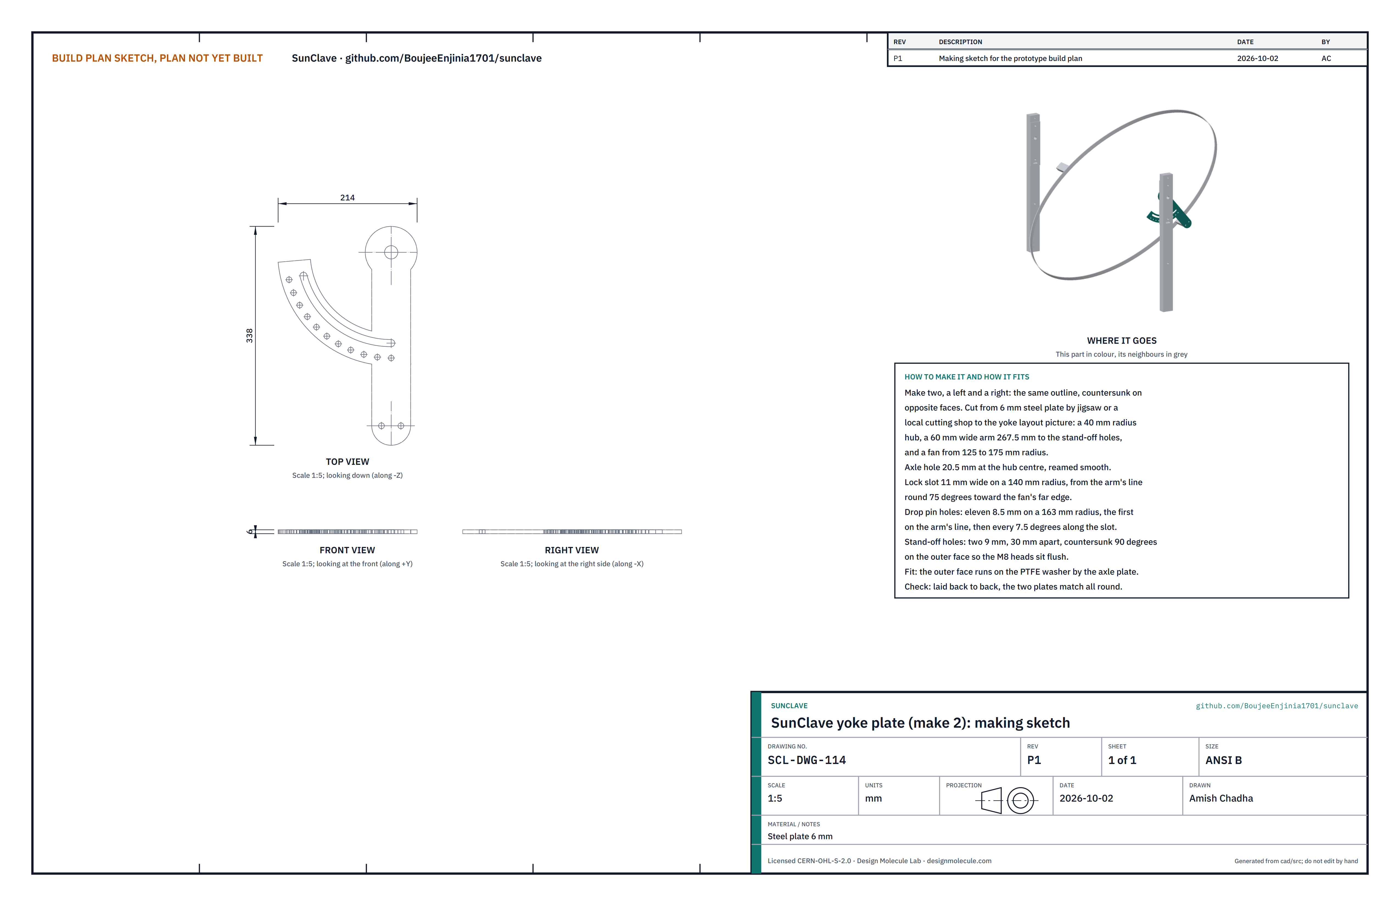
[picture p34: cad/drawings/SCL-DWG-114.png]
Figure 25. Making sketch of the yoke plate


*Figure 25. Yoke plate making sketch (SCL-DWG-114).*

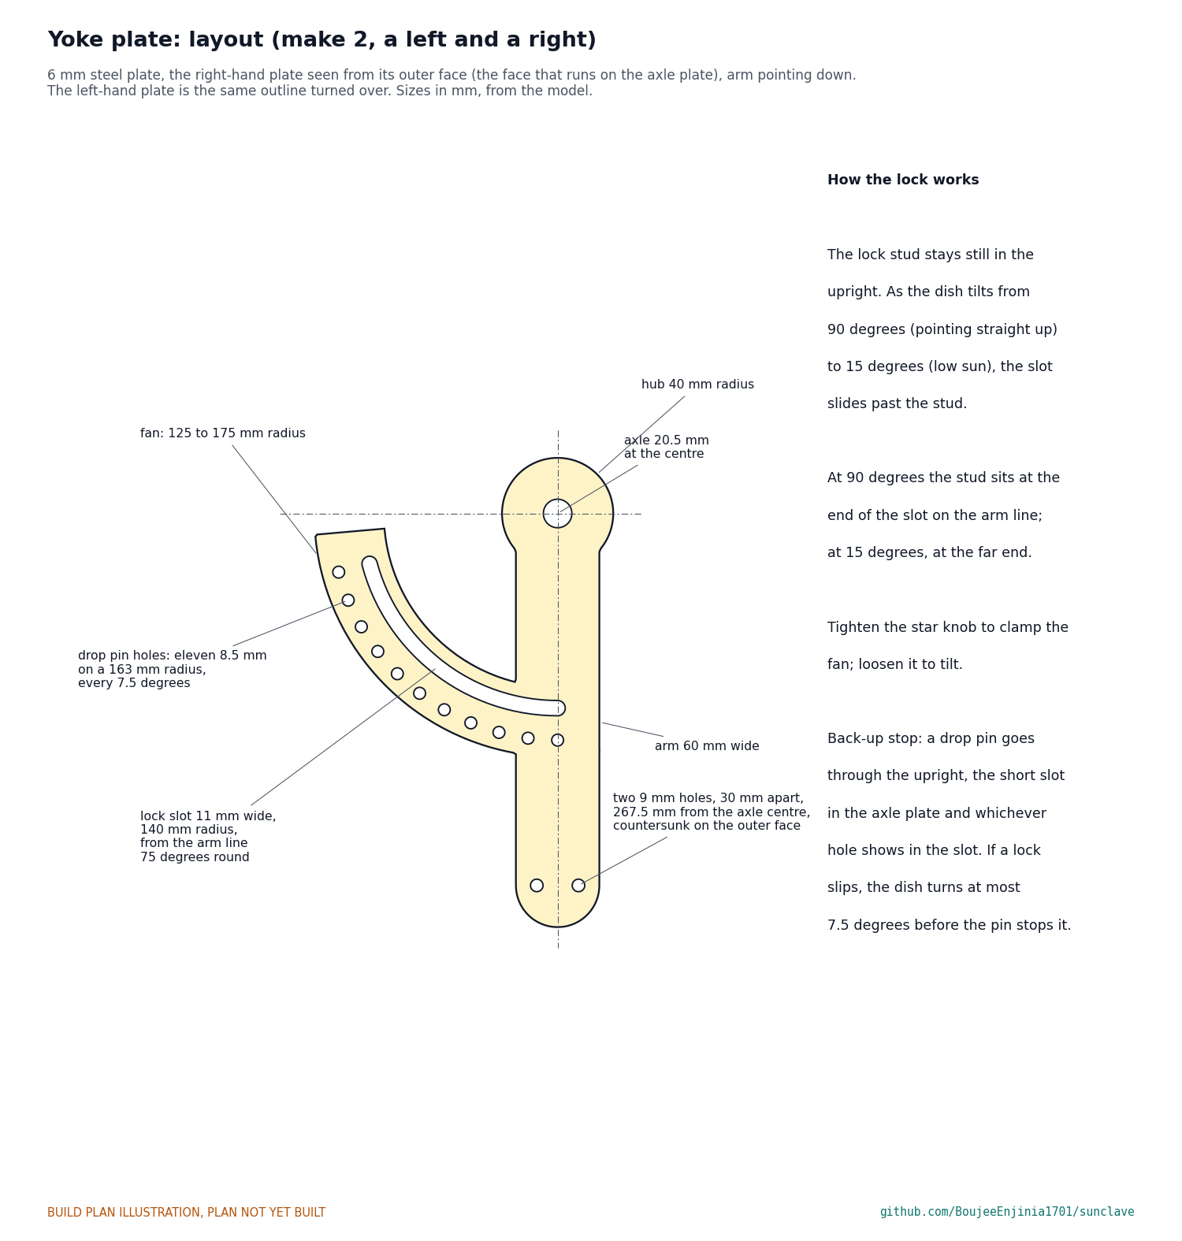
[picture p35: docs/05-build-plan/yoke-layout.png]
Figure 26. Yoke plate layout


*Figure 26. Yoke plate layout, with the lock slot and the row of drop pin holes.*

**What it is and what it is made from.** The plate each side that carries the dish on its axle: a hub round the axle, an arm down to the stand-off, and a fan with the lock slot and the drop pin holes. Steel plate 6 mm.

**How to make it.**

1. Cut the outline of Figure 26 from 6 mm plate with a jigsaw and metal blade, or have a local cutting shop cut both: a 40 mm radius hub, a 60 mm wide arm with a round end, and a fan from 125 to 175 mm radius.
2. Drill the axle hole 20.5 mm at the hub centre and smooth it with a round file or reamer.
3. Cut the lock slot, 11 mm wide on a 140 mm radius, from the arm's centre line 75 degrees round toward the fan's far edge: drill 11 mm at each end and chain-drill between, then file smooth.
4. Drill the drop pin holes: eleven holes of 8.5 mm on a 163 mm radius, the first on the arm's centre line and then every 7.5 degrees along the slot. Mark them with a protractor from the axle hole, or drill the two plates clamped together.
5. Drill the two stand-off holes, 9 mm, 30 mm apart across the arm, 267.5 mm from the axle centre. Countersink them 90 degrees on the outer face (the face toward the upright). The two plates are mirror images: the outer face of one is the face that is down when the other's is up.
6. Deburr and paint, leaving the outer face bare round the hub and over the fan.

**How it fits the parts next to it.**

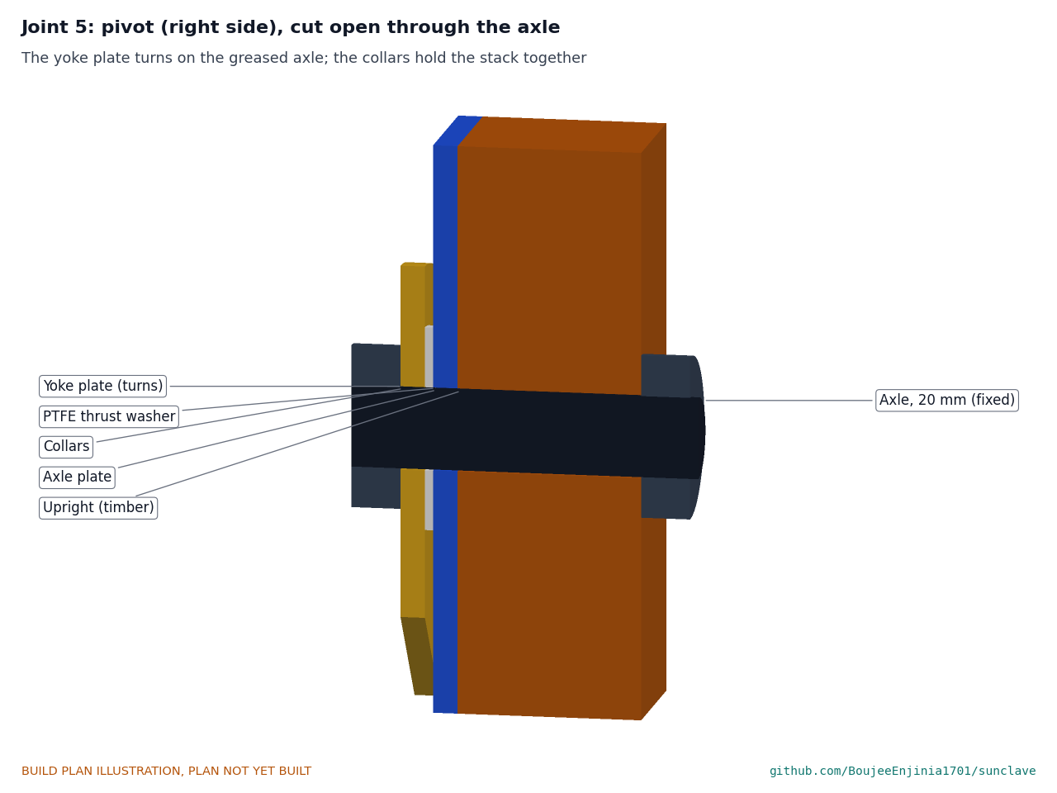
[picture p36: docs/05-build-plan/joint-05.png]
Figure 27. Joint 5: pivot, cut open


*Figure 27. The pivot, cut open through the axle: the yoke plate turns on the fixed axle; the PTFE washer and the collars hold the stack.*

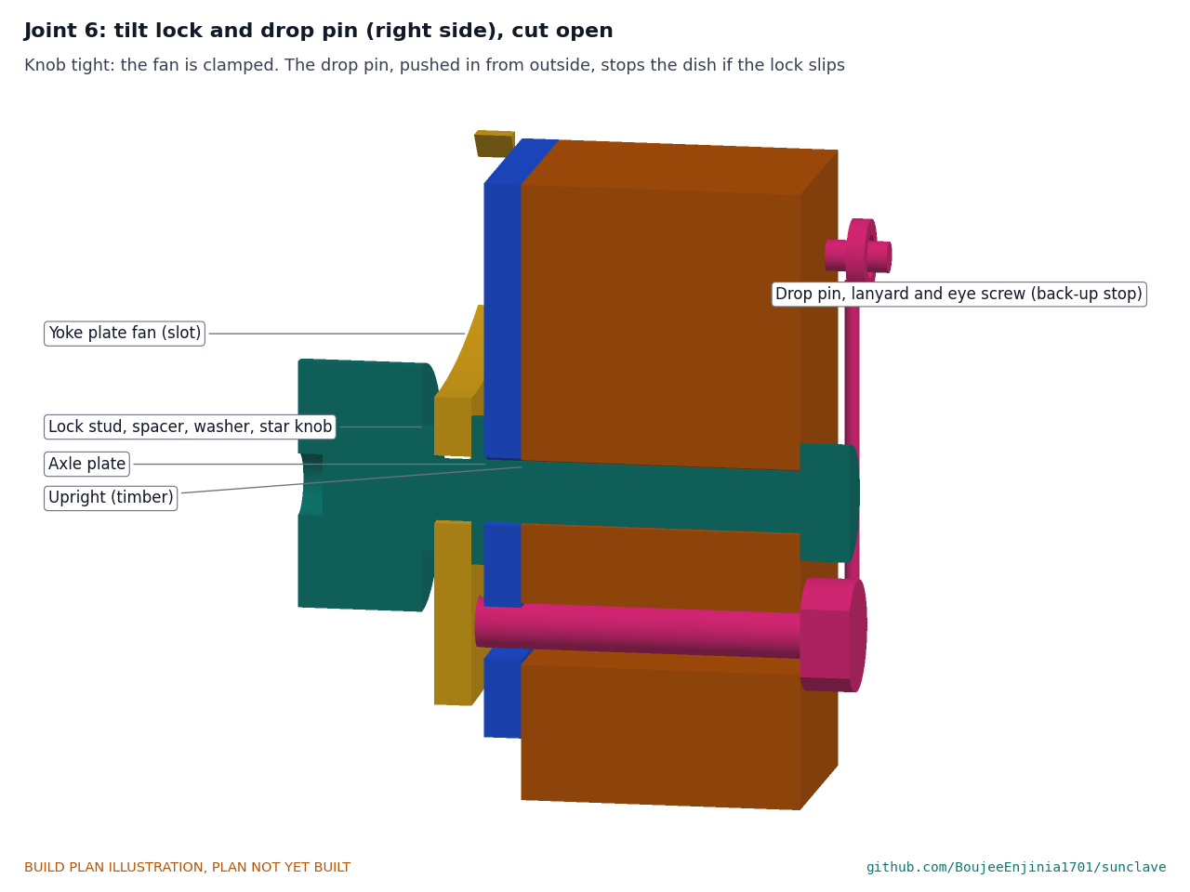
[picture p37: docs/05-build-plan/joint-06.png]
Figure 28. Joint 6: tilt lock, cut open


*Figure 28. The tilt lock and drop pin: the fixed stud passes through the slot in the yoke plate's fan, and tightening the star knob clamps the fan; the drop pin, pushed in from outside the upright, passes through the axle plate's short slot and one hole of the fan.*

The outer face runs against the PTFE washer on the axle plate, 2 mm from it; the axle passes through the hub; the lock stud passes through the slot, and the drop pin through whichever hole shows in the axle plate's slot (Figures 27 and 28). The arm's end carries the rim stand-off (Figure 24).

**Check before moving on.** Laid back to back, the two plates match all round, and each turns freely on a 20 mm bar.

### 3.15 Holder arms (make 2)

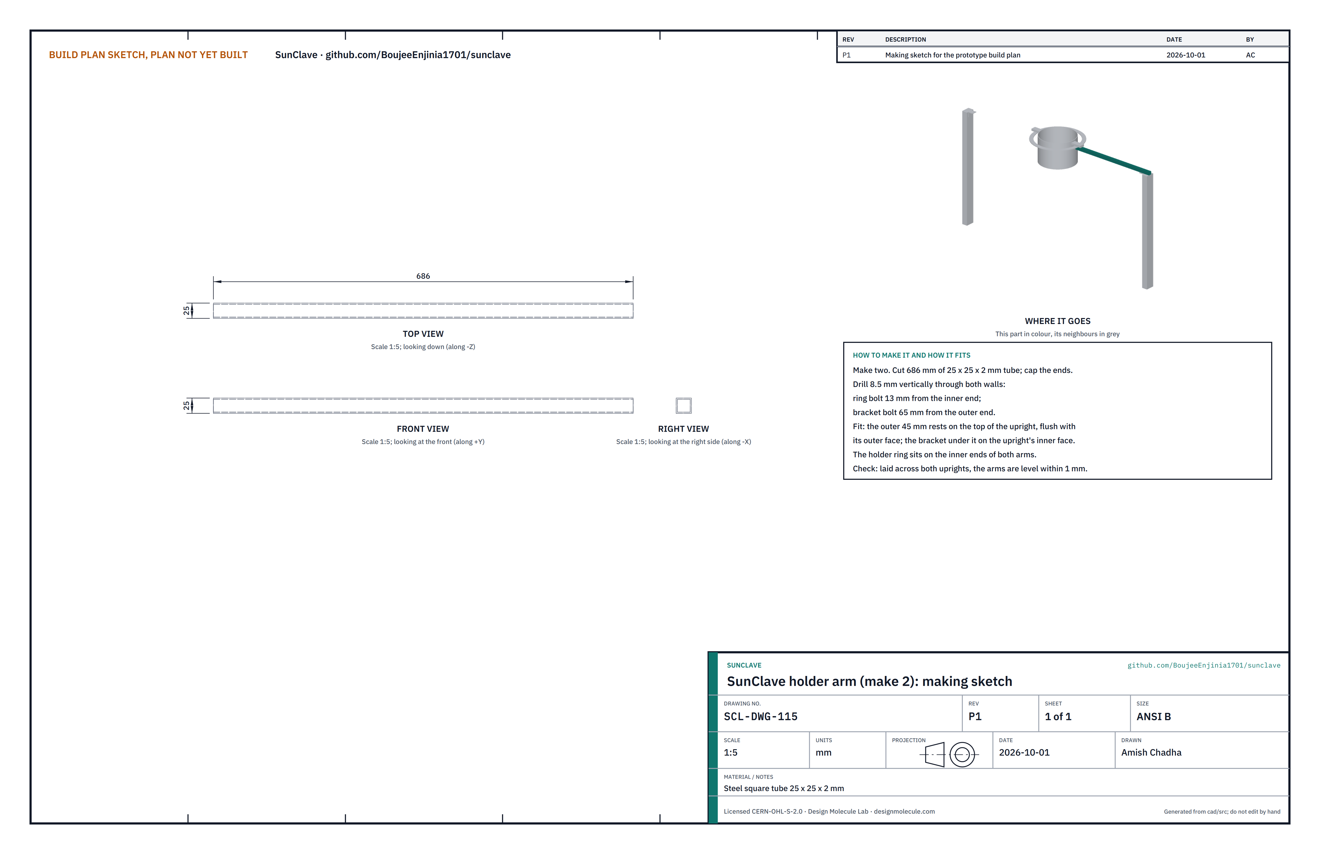
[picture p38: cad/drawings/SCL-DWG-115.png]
Figure 29. Making sketch of the holder arm


*Figure 29. Holder arm making sketch (SCL-DWG-115).*

**What it is and what it is made from.** The two bars that carry the holder ring between the tops of the uprights. Steel square tube 25 x 25 x 2 mm.

**How to make it.**

1. Cut 687 mm and fit plastic end caps.
2. Drill 8.5 mm vertically through both walls: one hole 13 mm from the inner end (ring bolt), one 65 mm from the outer end (bracket bolt).

**How it fits the parts next to it.** The outer 45 mm rests on the top of the upright, flush with its outer face, and on the flat leg of the arm bracket (Figure 31). The ring sits on the inner ends of both arms.

**Check before moving on.** Laid across both uprights, the two arms are level with each other within 1 mm.

### 3.16 Arm brackets (make 2)

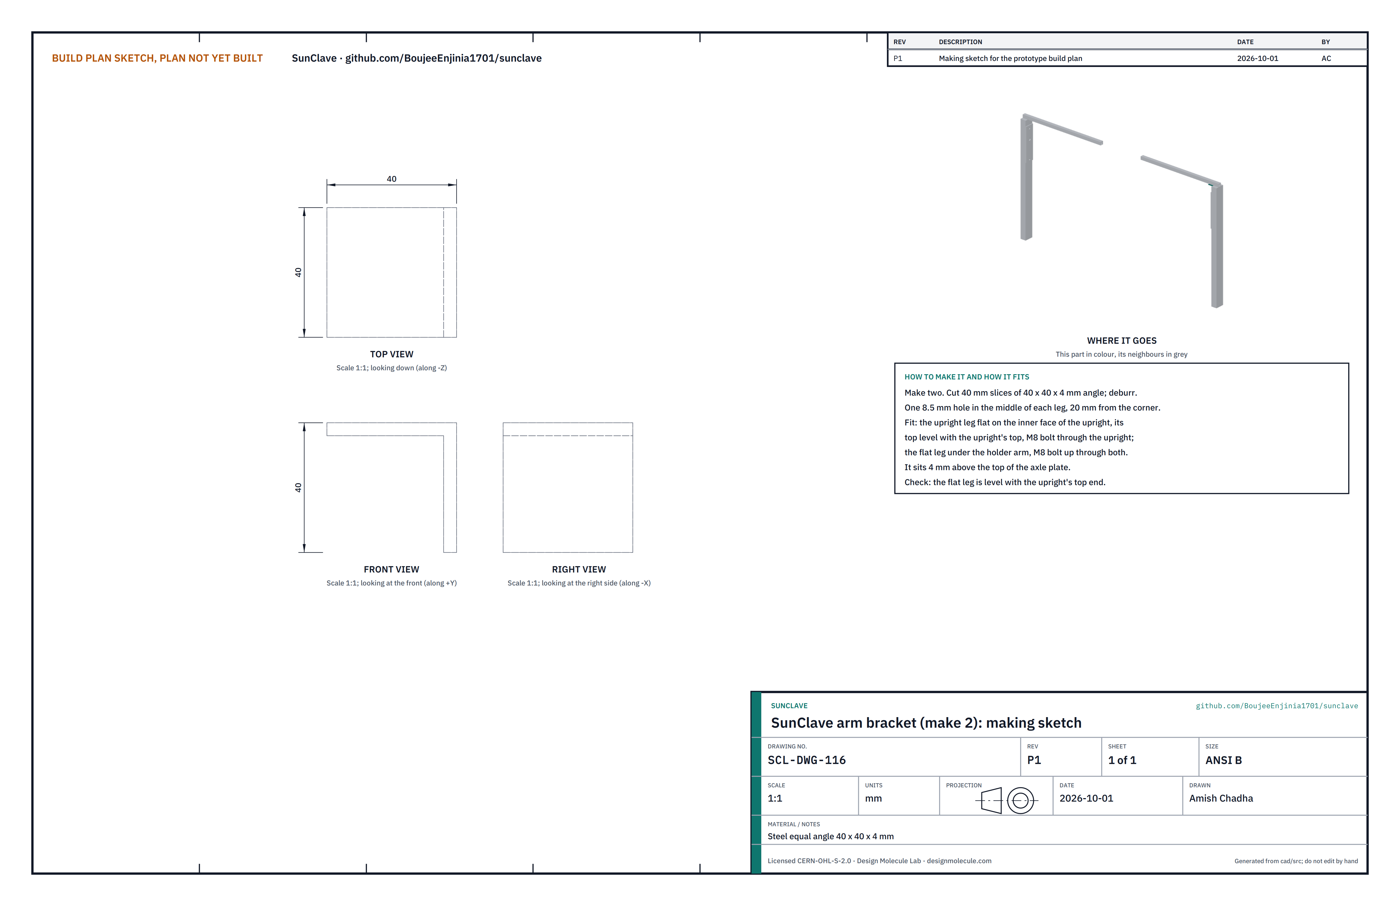
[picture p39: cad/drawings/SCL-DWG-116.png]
Figure 30. Making sketch of the arm bracket


*Figure 30. Arm bracket making sketch (SCL-DWG-116).*

**What it is and what it is made from.** A short angle on the inner face of each upright that the holder arm rests on. Steel equal angle 40 x 40 x 4 mm.

**How to make it.**

1. Cut 40 mm slices and deburr.
2. Drill one 8.5 mm hole in the middle of each leg, 20 mm from the corner.

**How it fits the parts next to it.**

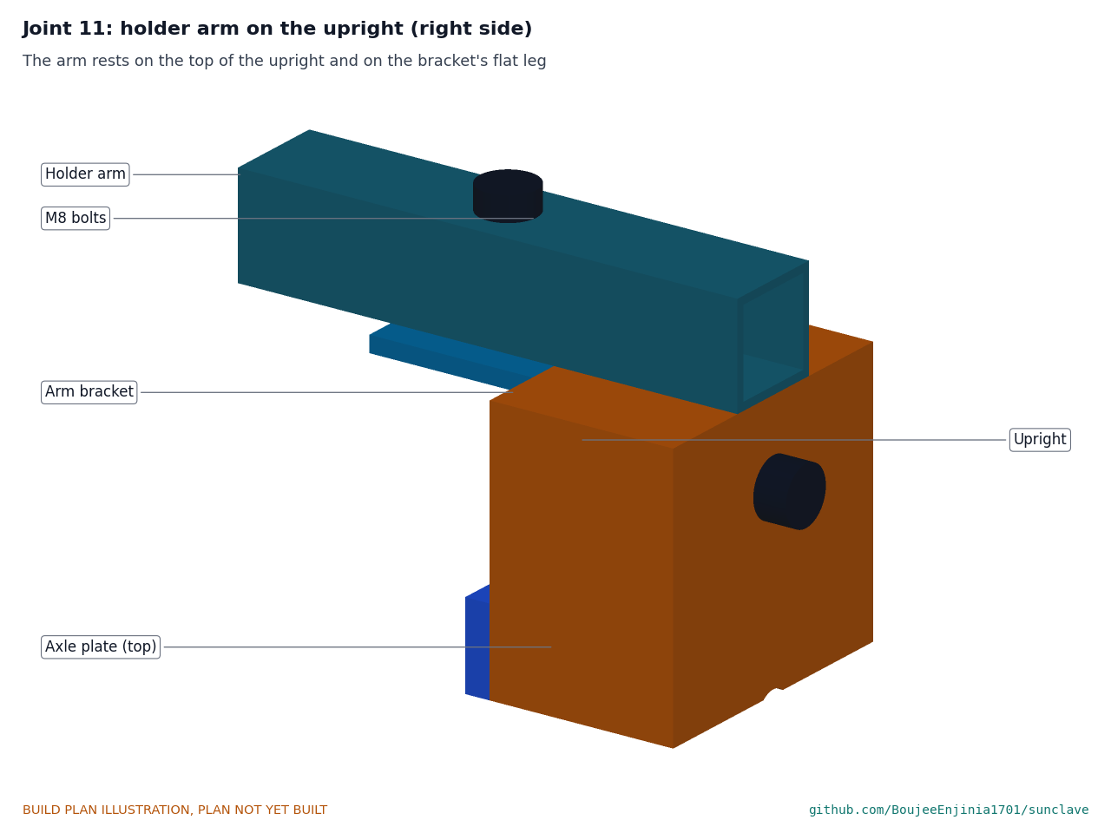
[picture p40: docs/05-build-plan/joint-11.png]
Figure 31. Joint 11: holder arm on the upright


*Figure 31. The arm rests on the top of the upright and on the bracket's flat leg; the bracket bolts through the upright, the arm bolts down through the bracket.*

The upright leg lies on the upright's inner face with its top level with the upright's top, held by one M8 bolt through the upright; the flat leg is under the arm, held by one M8 bolt up through both. It sits 4 mm above the top of the axle plate.

**Check before moving on.** The flat leg is level with the top of the upright.

### 3.17 Holder ring

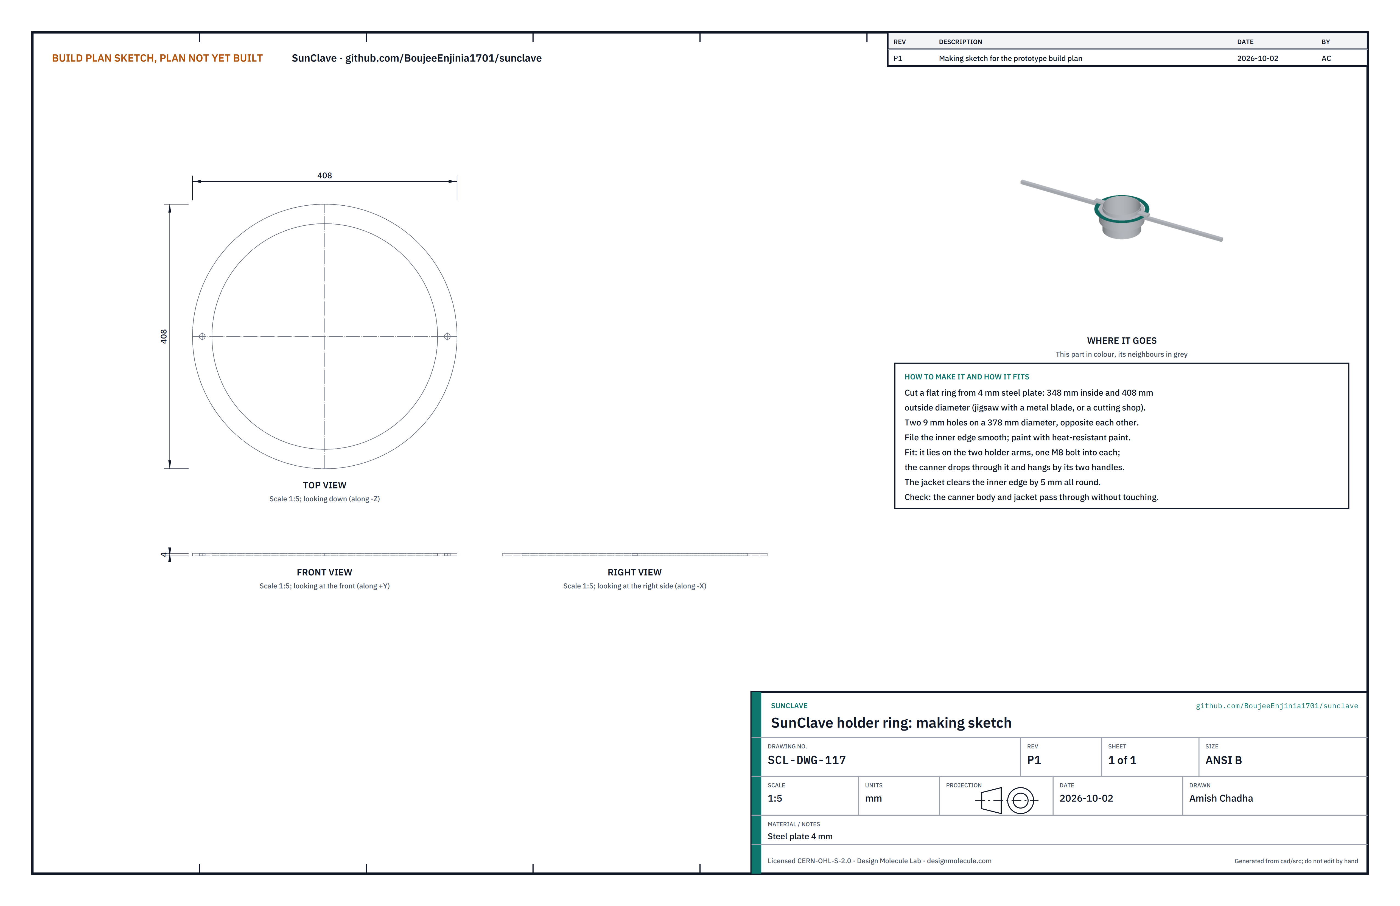
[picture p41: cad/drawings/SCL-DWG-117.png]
Figure 32. Making sketch of the holder ring


*Figure 32. Holder ring making sketch (SCL-DWG-117).*

**What it is and what it is made from.** The flat ring the canner hangs from by its two handles. Steel plate 4 mm.

**How to make it.**

1. Cut a flat ring 348 mm inside and 408 mm outside diameter, with a jigsaw and metal blade or at a local cutting shop.
2. Drill two 9 mm holes opposite each other on a 378 mm diameter.
3. File the inner edge smooth and paint with heat-resistant paint.

**How it fits the parts next to it.**

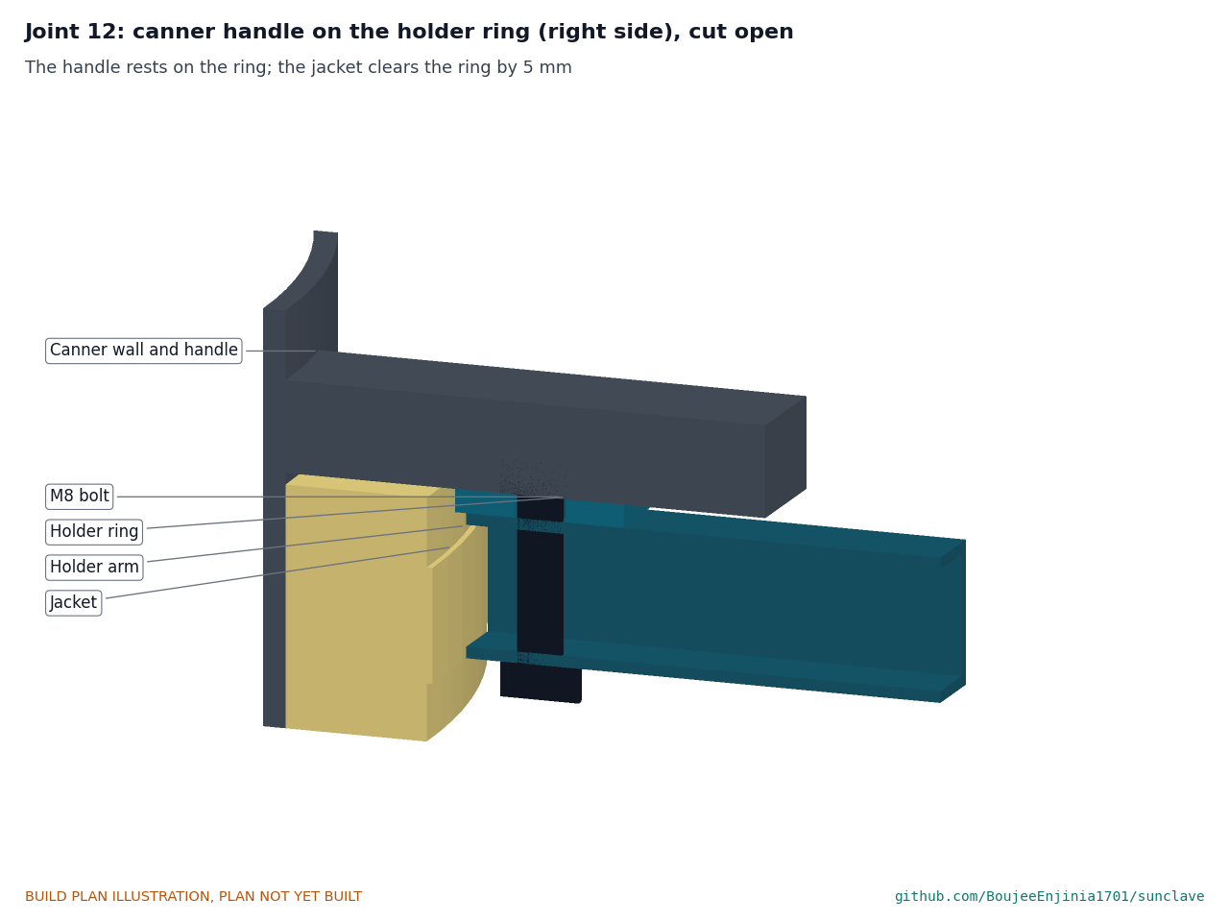
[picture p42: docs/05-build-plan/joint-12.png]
Figure 33. Joint 12: canner handle on the holder ring


*Figure 33. The canner's handle rests on the ring; the ring is bolted to the arm; the jacket clears the ring's inner edge by 5 mm.*

It lies on the inner ends of the two arms, one M8 bolt into each. The canner drops through it and hangs by its handles, so the canner's base sits on the focal plane.

**Check before moving on.** The canner body and jacket pass through without touching, and both handles rest on the ring.

### 3.18 Canner, jacket and base thermocouple

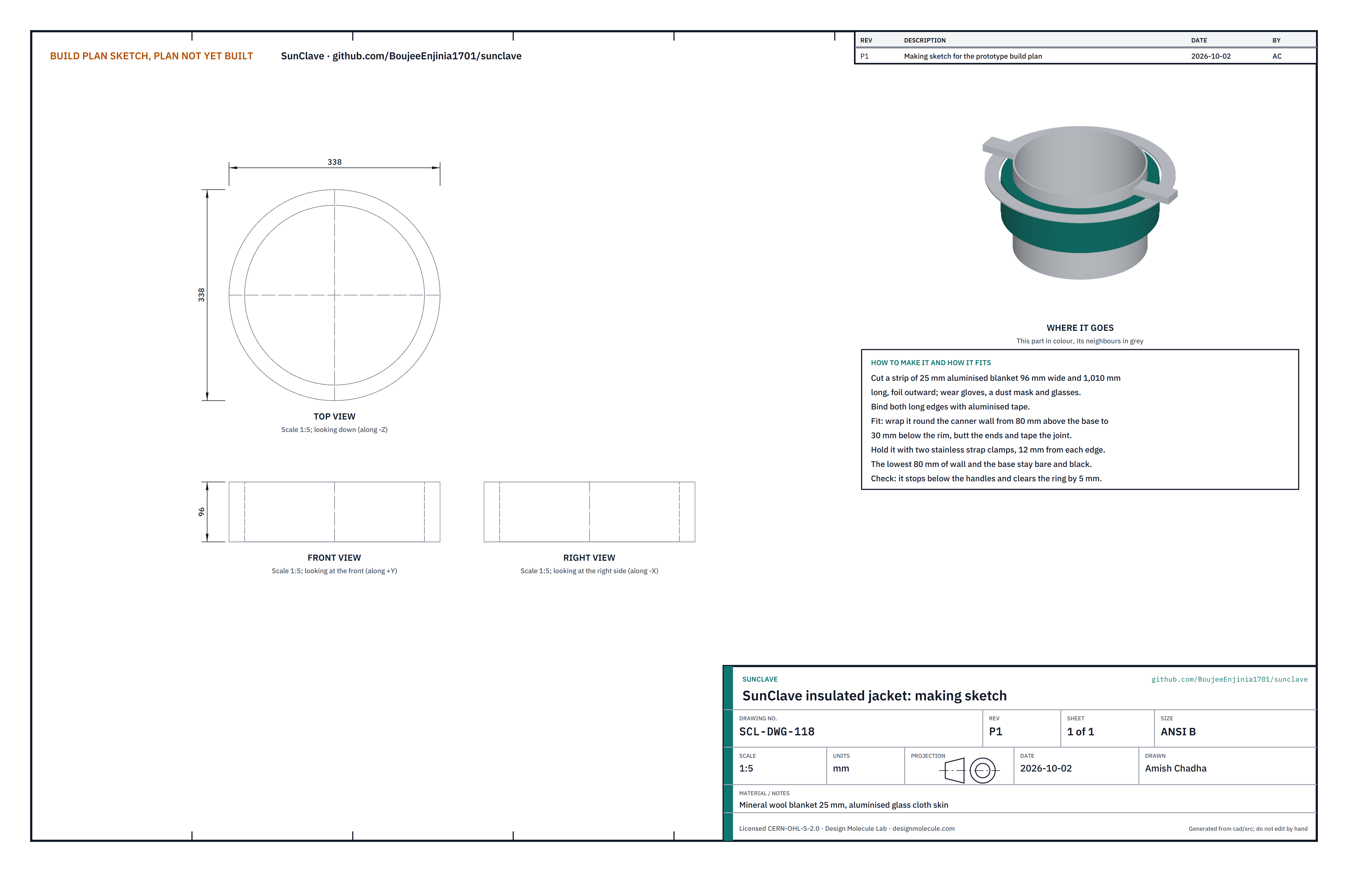
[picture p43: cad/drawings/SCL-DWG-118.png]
Figure 34. Making sketch of the jacket


*Figure 34. Jacket making sketch (SCL-DWG-118).*

**What it is and what it is made from.** The bought aluminium pressure canner of about 12 L, sold with its own gauge and relief valve, painted black where the sunlight lands, with an insulating jacket on its upper wall and a thermocouple at the edge of its base. The jacket is 25 mm mineral wool blanket with an aluminised glass-cloth skin.

**How to make it.**

1. Canner: clean the outside with detergent. Mask the rest and paint the base and the lowest 80 mm of the wall with high-temperature matt black paint; cure it as the paint maker says. Do not drill, weld or change the canner body, its lid, its regulator weight, gauge, relief valve or overpressure plug.
2. Jacket: cut a strip 96 mm wide and 1,010 mm long, foil outward, wearing gloves, a dust mask and glasses. Bind both long edges with aluminised tape.
3. Wrap the jacket round the wall from 80 mm above the base to 30 mm below the rim, butt and tape the joint, and hold it with two stainless strap clamps, 12 mm from each edge.
4. Thermocouple: hold its tip against the bare black wall 10 mm above the base with a stainless band clamp, on the side away from the logger, and lead the wire up beside the jacket.

**How it fits the parts next to it.** The handles rest on the holder ring (Figure 33); the jacket stops below the handles and clears the ring by 5 mm. The basket stands on its trivet inside, above the water.

**Check before moving on.** The paint is cured and unbroken, the jacket does not cover any of the black band, and the thermocouple reads room temperature on the logger.

### 3.19 Logger box

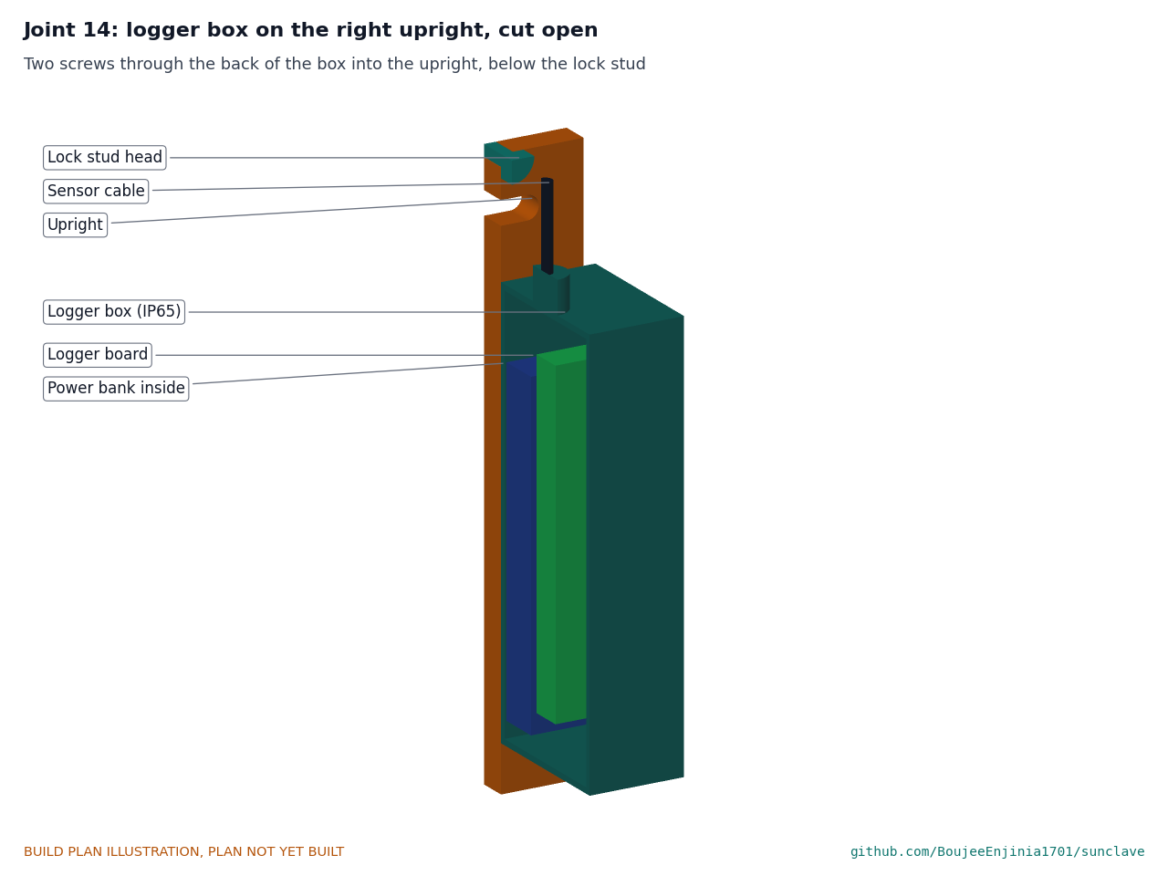
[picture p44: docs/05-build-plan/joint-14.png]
Figure 35. Joint 14: logger box on the right upright


*Figure 35. The logger box on the outer face of the right upright, cut open: the power bank at the back, the board in front, the sensor cable out of the top.*

**What it is and what it is made from.** A bought IP65 plastic box about 180 x 80 x 65 mm holding the logger board, its modules and display, and the power bank.

**How to make it.**

1. Drill the lid for the display window and the two buttons, and the top for one cable gland, following the box maker's advice for drilling.
2. Fit the board and modules on standoffs in front, and the power bank in a strap at the back.
3. Make up the sensor cable: Pt100 leads, transducer leads and thermocouple lead in one sheath, with a plug at the lid end so the lid comes off, and a plug at the box.

**How it fits the parts next to it.** Two stainless wood screws through the moulded holes in the back of the box go into the outer face of the right upright, the box's top about 18 mm below the drop pin's head and its bottom 580 mm above the ground. The cable runs up beside the upright, along the top of the right holder arm with cable ties, and up to the lid.

**Check before moving on.** The box closes on its gasket with the cable through the gland, and the display shows readings with the sensors plugged in.

### 3.20 Drop pins (make 2)

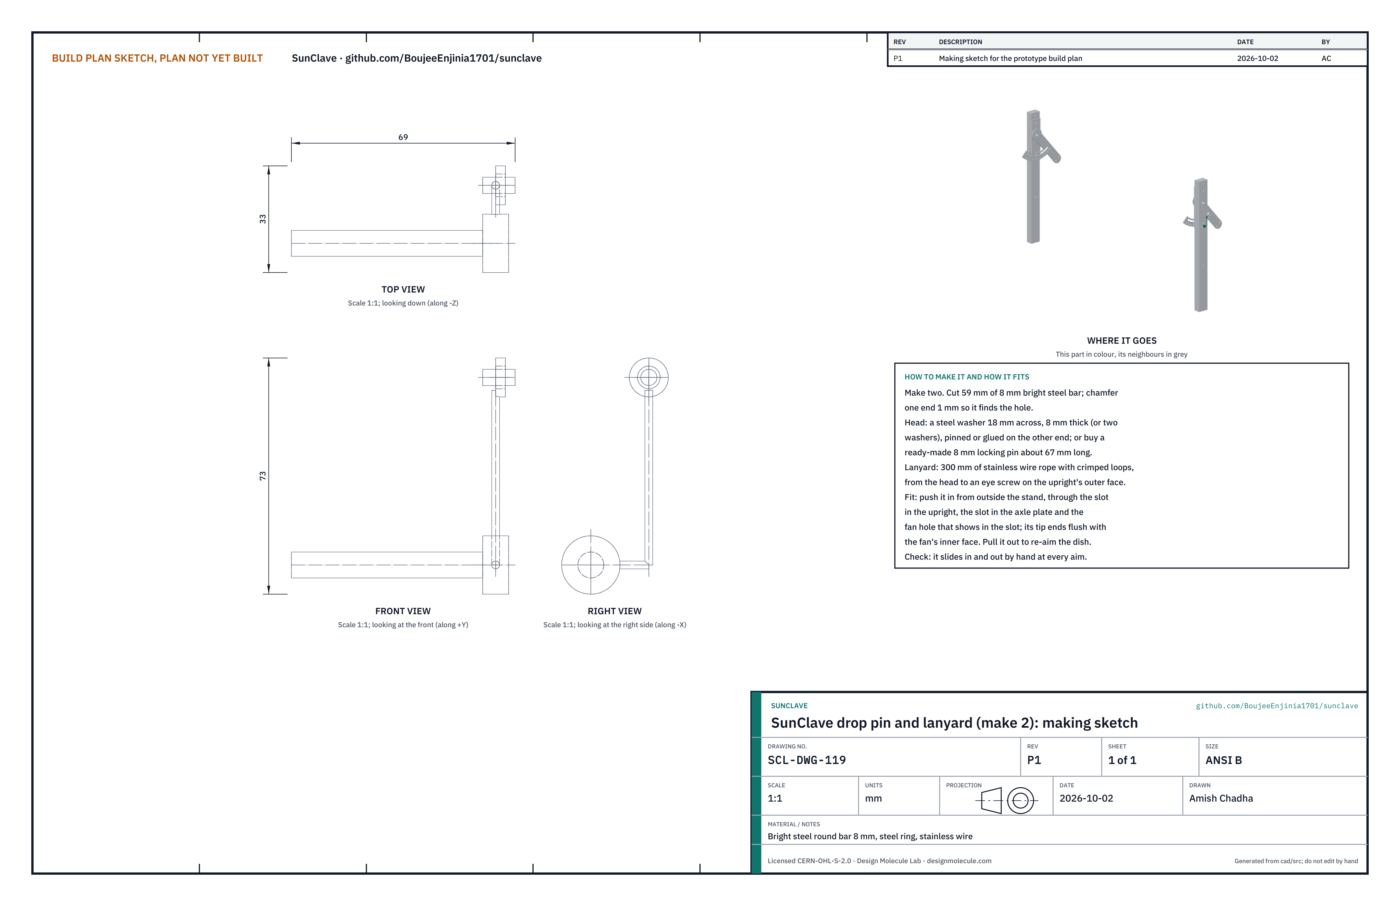
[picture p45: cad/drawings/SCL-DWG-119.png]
Figure 36. Making sketch of the drop pin


*Figure 36. Drop pin and lanyard making sketch (SCL-DWG-119).*

**What it is and what it is made from.** A back-up stop for each tilt lock: a short steel pin that goes through the upright, the axle plate and one hole of the yoke plate's fan. Bright steel round bar 8 mm, a steel washer head, and stainless wire rope for the lanyard. A ready-made 8 mm locking pin of the same length will do.

**How to make it.**

1. Cut 59 mm of 8 mm bright steel bar and chamfer one end by 1 mm (67 mm long with its head).
2. Fix a steel washer about 18 mm across and 8 mm thick to the other end as a head (a cross pin or high-strength adhesive).
3. Crimp a loop at each end of 300 mm of stainless wire rope; thread one loop under the head.

**How it fits the parts next to it.** With the dish aimed and the star knob tight, look through the slot in the upright: one hole of the fan shows in the axle plate's short slot. Push the pin in from outside until its head touches the upright; its tip ends flush with the fan's inner face (Figure 28). The other end of the lanyard goes on the eye screw on the upright, so the pin cannot be lost. If a lock slips, the dish turns at most 7.5 degrees before the pin reaches the end of the slot. Pull the pin out before loosening the knob to re-aim.

**Check before moving on.** At every aim from face up to 15 degrees above the horizon, a fan hole shows in the slot and the pin slides in and out by hand.

### 3.21 Vent-stem adapter plate

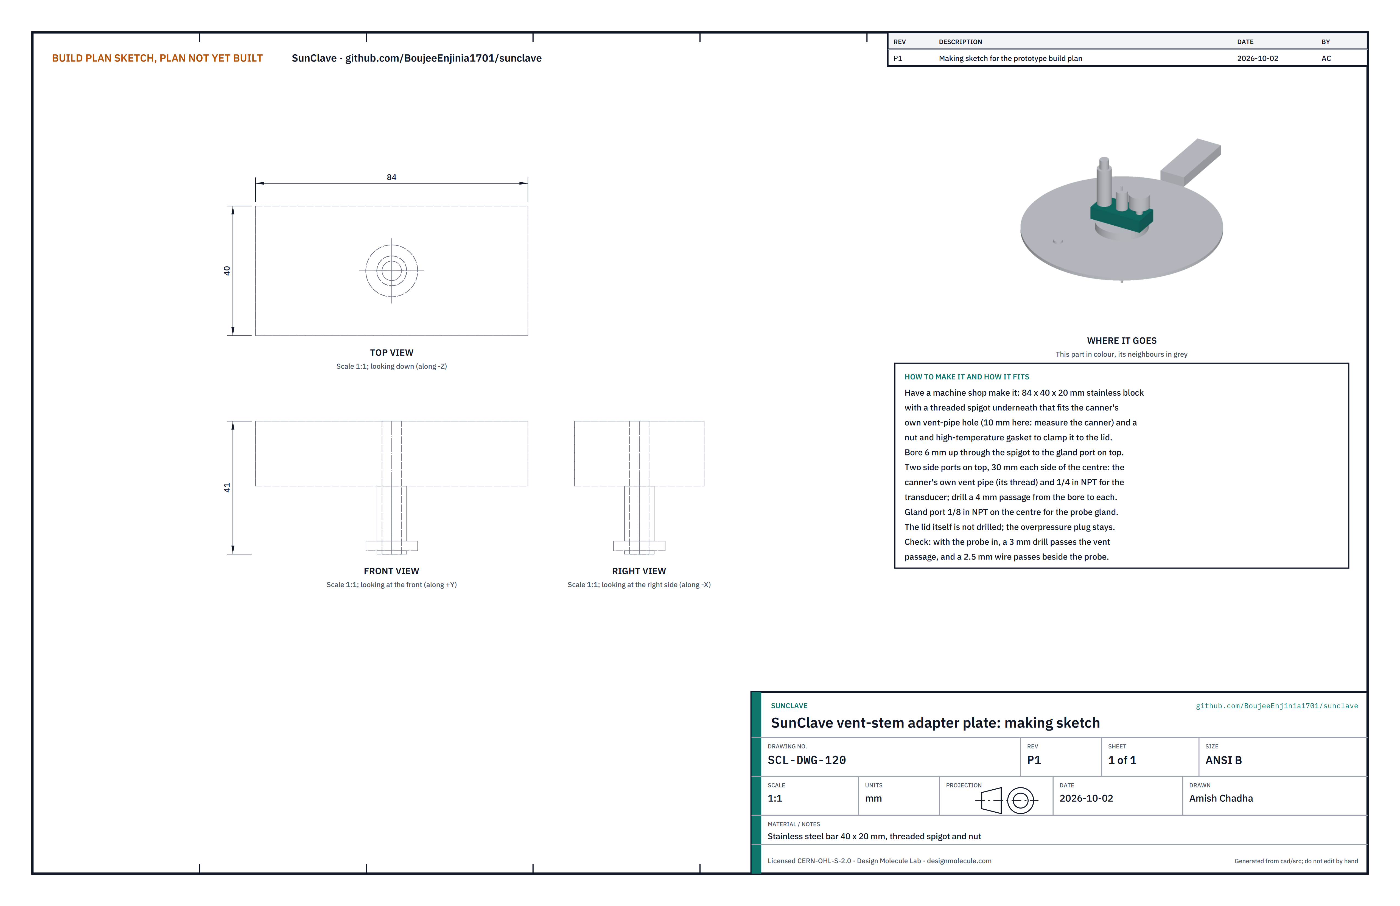
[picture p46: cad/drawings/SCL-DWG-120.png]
Figure 37. Making sketch of the vent-stem adapter plate


*Figure 37. Vent-stem adapter plate making sketch (SCL-DWG-120).*

**What it is and what it is made from.** A small stainless block that screws into the canner lid's own vent-pipe hole and carries the temperature probe's gland, the pressure sensor and, on top, the canner maker's own vent pipe and weight. Stainless steel bar 40 x 20 mm, made by a local machine shop.

**How to make it.**

1. Unscrew the canner maker's vent pipe and measure its thread and the hole it came out of. Take the canner lid, the vent pipe, the gland and the sensor to the machine shop.
2. Have the shop make the block 84 x 40 x 20 mm with a threaded spigot underneath that fits the lid's hole, a nut and a high-temperature gasket; a 6 mm bore up through the spigot to a gland port on top; and two ports on top, 30 mm each side of the centre, one for the maker's vent pipe (its own thread) and one for the pressure sensor, each joined to the bore by a 4 mm passage.
3. Do not drill or enlarge any hole in the lid, and do not touch the overpressure plug.

**How it fits the parts next to it.** The spigot goes down through the lid's vent-pipe hole and the nut clamps it from inside, on its gasket. The probe passes down through the gland and the 6 mm bore into the canner, and steam passes round it; the bore round the probe is as open as a 5.2 mm hole, more than the maker's own vent. The maker's vent pipe and weight go on top at one end, the pressure sensor at the other (Step 19).

**Check before moving on.** With the probe in its gland, a 3 mm drill passes along the vent passage, and a 2.5 mm wire passes down the bore beside the probe.

### 3.22 Bought components

Buy to specification, not brand. Line numbers are those of the bill of materials.

- **Castors (line 4).** Four 75 mm swivel castors with brakes, 102 mm mounting height, top plate with holes on a 42 mm square.
- **Pivot parts (line 4).** Four 20 mm shaft collars with set screws; two PTFE thrust washers 2 mm thick, 20.5 mm bore, about 50 mm outside diameter; four galvanised 50 x 50 mm angle brackets, 40 mm wide.
- **Lock parts (line 3).** Two M10 x 80 hex bolts, two 2 mm steel spacer washers (24 mm outside diameter), two M10 washers and two M10 star knobs; two eye screws and the drop pin lanyards.
- **Pressure canner (line 6, with its lid, line 7, and its own gauge and relief valve, lines 8 and 9).** Aluminium pressure canner of about 12 L sold with a dial gauge, a relief (safety) valve, a 103.4 kPa (15 psi) weighted regulator on a vent pipe and an overpressure plug; inside about 280 mm across and 200 mm deep; two handles on the body whose undersides are about 28 mm below the rim and reach at least 214 mm from the centre; maker's rating for 103.4 kPa published; relief valve set at 125 kPa gauge or less with a seat of 4 mm or more.
- **Probe and sensor (lines 10 and 14).** 1/8 in compression gland, 3 mm class A Pt100 probe with PTFE leads; 0 to 300 kPa absolute transducer rated to 600 kPa or more. They go on the adapter plate (section 3.21), never through the lid.
- **Basket (line 13).** Stainless wire basket 250 mm across and 150 mm deep on a 40 mm trivet.
- **Logger (line 14) and power bank (line 15).** As the bill of materials: ESP32-class board, Pt100 interface with a 0.05 % reference, 16-bit converter, real-time clock, microSD, 1.3 in OLED display, buzzer, K-type thermocouple with its interface; a 10,000 mAh power bank with a low-current mode.
- **Safety items (lines 19 to 21).** Two pairs of shade 5 goggles, an opaque parking cover for the dish, barrier tape and four pegs.
- **Fixings (line 17).** Stainless or galvanised: 16 M8 x 50 (castors); 8 M8 x 120 (crossings); 2 M8 x 90 horizontal and 4 M8 x 90 vertical (foot brackets); 2 M10 x 140 and 4 M10 x 100 (braces); 2 M10 x 70 (axle plates); 2 M8 x 70 and 4 M8 x 40 (arms and ring); two small eye screws (drop pin lanyards); 4 M8 x 120 countersunk (stand-offs); about 52 M5 x 16 (clips and rim joint); 2 M6 x 16 and 2 M5 x 12 (gnomon); nyloc nuts and washers for all; about 300 aluminium rivets 3.2 mm; two 5 x 40 stainless wood screws; cable ties; high-temperature paint; grease.

## 4. Putting it together

In each picture the parts already fitted are grey and the part being fitted is in colour, with an arrow showing the way it goes in. Steps 1 to 5 and 11 to 19 are on the stand; steps 6 to 10 build the dish face up on a level floor beside it.

### Step 1: castors onto the cross rails

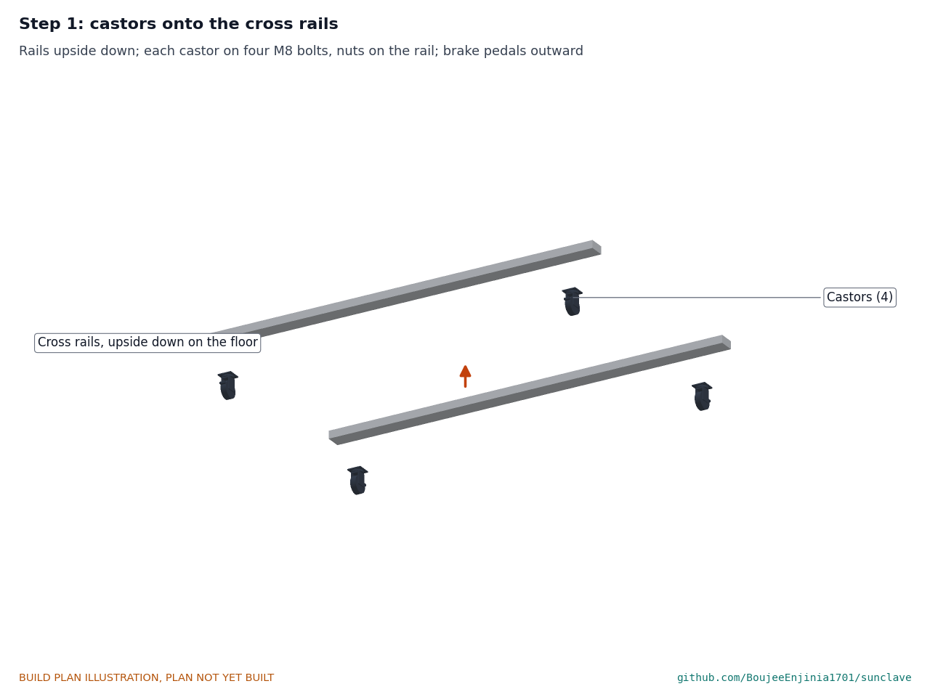
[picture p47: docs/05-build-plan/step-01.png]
Step 1


Rails upside down on the floor. Each castor on four M8 x 50 bolts, nuts and washers on the rail, brake pedals facing outward.

### Step 2: side rails across the cross rails

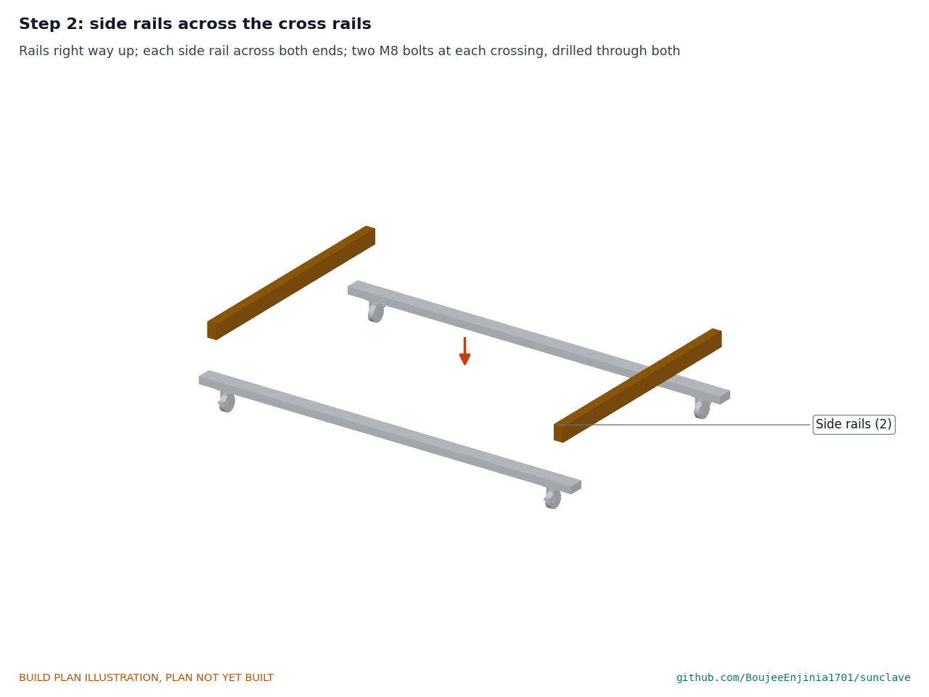
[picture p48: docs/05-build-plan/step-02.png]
Step 2


Rails right way up, castors on the floor, brakes on. Lay each side rail on edge across both cross rails, its outer face 40 mm in from the rail ends; check the frame is square (equal diagonals within 3 mm), clamp, drill the crossing holes through both and fit two M8 x 120 bolts at each crossing.

### Step 3: uprights onto the side rails

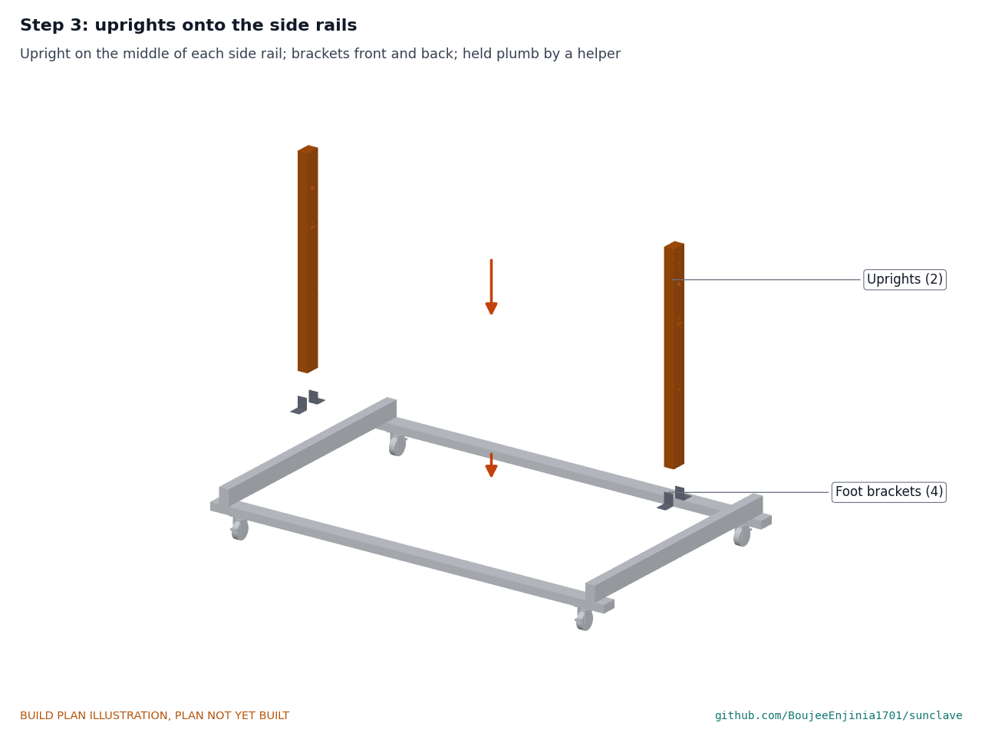
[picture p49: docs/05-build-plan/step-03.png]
Step 3


Stand each upright on the middle of its side rail, the 45 mm face toward the other upright and its axle hole level with the other's. Fit the two angle brackets on its front and back faces, one M8 x 90 through the upright and both brackets, one M8 x 90 down through each bracket and the side rail. A helper holds it plumb.

### Step 4: braces

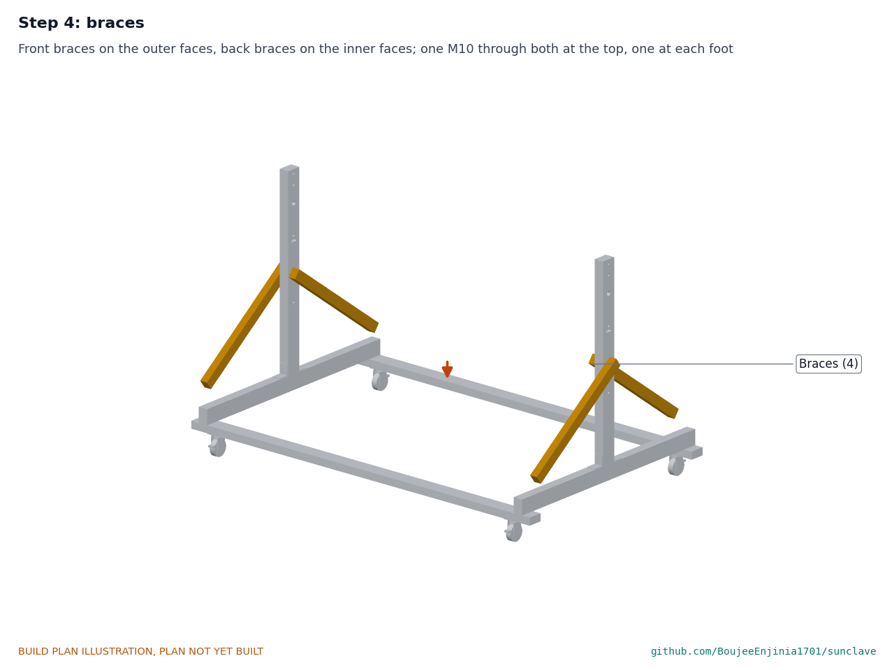
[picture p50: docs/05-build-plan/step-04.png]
Step 4


Front braces on the outer faces, back braces on the inner faces. One M10 x 140 through both braces and the upright at the top; one M10 x 100 at each foot. Check plumb on both faces, then tighten.

### Step 5: left axle plate

Step 5

On the inner face of the left upright, holes on the upright's holes, M10 x 70 at the top with the nut inside. Leave the right axle plate off for now.

### Step 6: ribs onto the hub plate

Step 6

Dish face up on a level floor: hub plate on a block so its front is about 267 mm below the top of the rim, each rib propped on its jig or a stand. Each rib's inner end on the hub plate beside its line; one clip and two M5 bolts each, finger tight.

### Step 7: rim band onto the rib ends

Step 7

Rim band round the rib ends, its joint strap at a rib and its top edge level with the rib tops. One rim clip and two M5 bolts at each rib, finger tight. Check the band is round and level, then tighten the hub and rim bolts.

### Step 8: petals onto the ribs

Step 8

Fit two opposite petals first, then their neighbours, working round. Each petal's flanges outside its two ribs; drill 3.3 mm through flange, rib and the next flange every 50 mm and rivet. Rivet the tabs inside the rim band. At each rim clip, the clip's bolt goes through clip, flange, rib and flange. Peel the film last.

### Step 9: gnomon onto the rim band

Step 9

At the gnomon position, two M6 bolts through the band; plate on the flat leg with two M5 bolts; check the pin is square to the rim plane.

### Step 10: stand-offs and yoke plates onto the rim band

Step 10

At each stand-off position, opposite each other: yoke plate, stand-off and band clamped by two M8 x 120 countersunk screws, heads flush on the yoke plate's outer face, nyloc nuts inside the band. The arms point down toward the dish's back, the fans toward the gnomon side. **Hold point:** safety stop S1.

### Step 11: dish into the stand

Step 11

Two people lift the dish by the rim, face up, and lower it from above between the uprights until the yoke plates' axle holes line up with the uprights' holes; prop it on blocks there. The left yoke plate sits 2 mm from the left axle plate.

### Step 12: right axle plate

Step 12

Slide the right axle plate down between the right yoke plate and the right upright, holes on the upright's holes, and fit its M10 x 70 at the top.

### Step 13: axles, thrust washers and collars

Step 13

Grease each axle. Hold a PTFE washer between the axle plate and the yoke plate and push the axle in from outside, through the upright, plate, washer and yoke plate, into the inner collar; set the outer collar against the upright and both set screws on their flats, leaving the yoke plate free to turn. **Hold point:** safety stop S2.

### Step 14: lock studs, star knobs and drop pins

Step 14

Each M10 x 80 stud in from outside through the upright and the axle plate, the 2 mm spacer behind the yoke plate's slot, then through the slot; washer and star knob in front. Tilt the dish through its whole range by hand with the knobs loose, then lock it face up. Hang each drop pin's lanyard on its eye screw and push the pin in from outside through the slot in the upright and the fan hole that shows in the axle plate's slot.

### Step 15: holder arms

Step 15

Arm brackets on the inner faces of the uprights, M8 x 70 through each upright. Each arm on its upright's top and bracket, flush with the outer face; M8 x 40 up through the bracket and arm.

### Step 16: holder ring

Step 16

On the inner ends of both arms, one M8 x 40 into each.

### Step 17: logger box

Step 17

On the outer face of the right upright, below the drop pin, two stainless wood screws. Cable along the right arm with cable ties.

### Step 18: canner into the holder ring

Step 18

With the dish turned away from the sun or covered: water and basket in, then lower the canner straight down through the ring until both handles rest on it. **Hold point:** safety stops S3 and S4.

### Step 19: lid, adapter plate and sensor cable

Step 19

The lid keeps its own gauge and relief valve as supplied. Fit the adapter plate in the lid's vent-pipe hole on its gasket and tighten the nut from inside; screw the maker's vent pipe into the plate's end port and put the weight on it; fit the probe through its gland and the pressure sensor in the other port. Close the lid as the canner maker says, and plug the sensor cable into the sensor lead at the lid and into the logger box. **Hold point:** safety stop S6: the canner is not pressurised under this plan.

## 5. First checks

These are the checks a TRL 4 test report would record; this plan only lists them. Requirement numbers are those of SCL-REQ-001.

*Table 2. First checks.*

| Check | Requirement | How | Pass when |
| --- | --- | --- | --- |
| Tilt range and clearances | R9, R14 | Knobs loose, tilt the dish by hand from face up to 15 degrees above horizontal | It moves smoothly; nothing rubs or comes within 5 mm of anything except the yoke plate passing its axle plate |
| Tilt lock holds | R9, R15 | Lock at 15 degrees with both drop pins in; hang a 5 kg bag from the rim at the gnomon; then loosen the knobs with the pins still in | Knobs tight: the dish does not move. Knobs loose: it turns no more than 7.5 degrees before the pins stop it. Pins out: it moves freely |
| Focus height | R4 | Dish face up, string across the rim; measure from the string to the canner base along the axis | 255 mm, give or take 3 mm |
| Gnomon alignment | R14 | Shine a torch along the dish axis from 3 m away, or check the pin square to the rim plane | The pin's shadow falls inside the 10 mm ring |
| Canner seating | R2 | Lower the canner with its basket and jacket through the ring | Both handles rest on the ring; the jacket clears the ring all round |
| Castor brakes | R15 | All four brakes on; push the stand at the top of an upright | It does not roll |
| Mass and pieces | R16 | Weigh the parts on a bathroom scale before assembly | 45 kg or less in all (44.8 kg estimated); no piece over 20 kg |
| Logger on its power bank | R6, R7, R13 | Power on in the shade; read the probe in iced water and in boiling water, and the transducer against a barometer | Readings within 0.5 °C of the reference after the boiling-point correction, and within 5 kPa; a record is written to the card |
| Parking cover and keep-out | R9, R11 | Fit the cover; peg out the 2 m keep-out | The cover closes the whole aperture; the tape marks 2 m round the dish and canner |

## 6. Safety stops

Stop at each point. Carry on only when everything listed is true.

- **S1. Before the dish is lifted into the stand.** Two people available; castor brakes on; the stand on level ground; cut-resistant gloves on; the dish indoors or face down, or covered, so it cannot catch the sun.
- **S2. Before the dish is let go on its axles.** Both axles in with both collars set; both lock studs and knobs fitted; hands kept clear of the fans and slots, which close like scissors as the dish tilts.
- **S3. Before the dish ever faces the sun.** The parking cover is at hand; everyone near wears the shade 5 goggles; the 2 m keep-out is pegged; nothing that can burn is under or near the dish; aiming is by the gnomon's shadow only, never by looking at the sun or the focus; the timber is checked for scorch marks after every session.
- **S4. Before the canner is at the focus in sun.** At least 1.5 L of water is in it; the thermocouple and logger are working and the 140 °C alarm sounds when tested; the dish is turned at least 15 degrees off the sun before anyone reaches toward the canner; heat-resistant gloves on.
- **S5. Before the power bank goes outside.** It sits in the shaded logger box, closed on its gasket; it is never charged above 45 °C.
- **S6. Before the canner is ever pressurised (outside this plan).** The lid has not been drilled (unless its maker has approved it in writing); the canner's own gauge and relief valve are in place as supplied, and the gauge has been checked against a reference; the adapter plate is in the vent-pipe hole, with a 3 mm drill passing its vent passage; the overpressure plug is untouched; the canner maker's rating for 103.4 kPa is confirmed; the relief valve's set pressure (125 kPa gauge or less) and seat (4 mm or more) are confirmed; and a hydrostatic check of the vessel as fitted has passed (TRL 4 work).

## 7. Tools, skills and workspace

**Tools.** Handsaw or circular saw for timber; hacksaw with a 24 teeth per inch blade; jigsaw with metal blades; bench drill or a drill in a stand; drills 3 to 12 mm and 20.5 mm (or a step drill), a 6 mm long pilot drill; 90 degree countersink; flat, half-round and round files; deburring tool; aviation snips; hand seamer for folding thin sheet; hand rivet tool for 3.2 mm rivets; spanners and sockets 8, 10, 13 and 17 mm, hex keys for the collar set screws; clamps; tape measure, steel rule, engineer's square, spirit level and calipers; 18 mm plywood, hardwood blocks and screws for the rib jig; bathroom scale; multimeter.

**Skills.** No certified trade is needed. Basic woodwork and metalwork (marking out, sawing, drilling, filing), folding and riveting thin sheet, and plugging together bought electronic modules. Nothing is welded and no mains wiring is involved. Pressure work is not part of this plan.

**Workspace.** A level floor about 3 x 3 m to build the dish and stand; a bench about 1.5 x 0.6 m; a ventilated, shaded place to paint; a clean area for the petals away from metal chips; a shaded place for the logger and power bank.

**Personal protective equipment.** Safety glasses for sawing, drilling and riveting; cut-resistant gloves for sheet and bar; hearing protection when sawing; dust mask, gloves and glasses for the mineral wool; shade 5 goggles near the focus; heat-resistant gloves for the canner; no gloves near a turning drill.

## 8. Where the numbers come from

- Model and constructability checks: `cad/src/model.py` (`python cad/src/model.py --check`, 66 checks); STEP and STL exports in `cad/step/` and `cad/stl/`.
- Pictures: `cad/src/build_plan_media.py`, using `.kit/build_views.py`; written to `docs/05-build-plan/` and `cad/drawings/SCL-DWG-101` to `SCL-DWG-120`.
- General arrangement: `cad/drawings/SCL-DWG-001.pdf`, Rev P3.
- Calculations: `docs/04-calcs/01-sizing.md` (SCL-CAL-001 v0.3) and `docs/04-calcs/sizing.py`; masses, tilt torque and lock force in section 10.
- Bill of materials: `bom/bom.csv`.
- Decisions: `docs/decisions/0003-design-for-construction.md` (SCL-DDR-003), with SCL-DDR-001 and SCL-DDR-002; open decisions in `docs/06-design-decisions.md` (SCL-DEC-001).
- Requirements: `docs/03-requirements.md` (SCL-REQ-001 v0.5).

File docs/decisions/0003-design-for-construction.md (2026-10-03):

---
doc_id: SCL-DDR-003
title: SunClave design for construction
project: SunClave
doc_type: Design decision record
version: "0.3"
status: Draft
date: '2026-10-02'
author: Amish Chadha
license: CERN-OHL-S-2.0
revisions:
- version: "0.1"
  date: '2026-10-01'
  author: Amish Chadha
  change: Changes that make the concept physically buildable, with the reason for each; made under Amish's 2026-09-30 instruction to make the design physically buildable; open for his review
- version: "0.2"
  date: '2026-10-02'
  author: Amish Chadha
  change: Accepted by Amish; A1 accepted and A2 decided with a back-up drop pin (changed recommendation)
- version: "0.3"
  date: '2026-10-02'
  author: Amish Chadha
  change: "Consequences updated: the canner, adapter plate and drop pins are in the model (SCL-CAL-001 v0.4); appearance model updated"
---

# 0003: Design for construction

- **Date:** 2026-10-01
- **Status:** accepted. Amish, 2026-10-02: "i approve your recommendations for all 555 open decisions." This covers every change in Tables 1 and 2 and the recommendations for A1 and A2 in Table 3 as written for the register on 2026-10-01 (SCL-DEC-001); A2 was changed to add a back-up drop pin. The changes were made under Amish's 2026-09-30 instruction to make the design physically buildable.

> **Safety:** SunClave is a research and educational prototype, not a medical device. Nothing in this record changes the pressure vessel, its regulator, the relief valve, the lid fittings or the hot-zone rules. The tilt lock and the pivots carry the dish's weight; they are pinch points and are covered by the safety stops in the build plan (SCL-BLD-001).

## Context

On 2026-09-30 Amish asked for every repo to get a prototype build plan that shows how each component is made and how it fits the next, with pictures, and wrote: "If you are realising that the design cannot be built as per concept - fix the design assumptions to match and be physically feasible as you draw the illustrations." The TRL 3 model of SCL-DDR-002 showed what SunClave does but was a massing model: checking it with build123d found parts that overlap, parts that float with no fixing, and parts that cannot be made or assembled as drawn (C1 to C9 below).

The changes keep what SunClave does: the same 1.4 m dish with a 500 mm focal length, the same focal height (950 mm) and tilt axis, the same 15 to 90 degree tilt range, the same 12 L cooker held level at the focus with its base on the focal plane, the same lid fittings, logger, power bank, gnomon aiming and four locking castors. Nothing here changes the pitch or the safety case. Every change is in `cad/src/model.py`, which now runs 66 constructability checks (`python cad/src/model.py --check`): parts that must touch do touch, parts that must stay apart are apart by the stated clearance, and every moving part stays at least 5 mm clear of every fixed part at 15, 30, 45, 60, 75 and 90 degrees of tilt (2 mm for the yoke plate running past its axle plate, by design). All 66 pass.

## Decision

*Table 1. Problems found in the concept model and the changes made to the model, the BOM and the calculations.*

| # | Problem in the concept | Change made | Why this way |
| --- | --- | --- | --- |
| C1 | Pivot and lock: the slotted quadrant plate, the lock lever and the yoke collars all passed through the steel bearing blocks (133 cm³ of overlap); the quadrant floated 11 mm off the upright, and a stub axle in a block had no stated way to carry the yoke. | Each side now has a 6 mm steel axle plate (70 x 270 mm) on the inner face of the upright, a fixed 20 mm steel axle through the upright and plate held by two shaft collars, a 2 mm PTFE thrust washer, and a 6 mm steel yoke plate that turns on the greased axle (a plain pivot, like a gate hinge). The quadrant becomes a fan on each yoke plate with an 11 mm slot on a 150 mm radius; an M10 stud through the upright, the plate and the slot, with a spacer and a star knob, clamps the fan. Both sides lock. | The dish moves a few degrees every 12 min, so a greased plain pivot is enough and needs no bought bearing. Putting the slot on the moving plate lets the fixed stud pass through the timber with its head outside, where there is room. Two locks clamp the dish evenly; at 252 N each they hold the 45 N·m worst gravity torque, and a hand-tight M10 gives about 2,000 N. |
| C2 | The yoke arms (20 mm tubes) stopped 2.2 mm short of the rim; the arms and rim had no joint. A single bolt at each rim point would have let the dish swing about the line through both bolts. | A rim stand-off (50 x 25 x 2.5 mm rectangular tube, 99.5 mm long) each side between the rim band and the end of the yoke plate's arm, clamped by two M8 countersunk screws 30 mm apart with nyloc nuts inside the band. | Two screws per side, spaced across the arm, make the dish and yoke one rigid unit. Countersunk heads keep the yoke plate's outer face flush, so it can pass the upright 6 mm away. |
| C3 | Pot holder: the ring overlapped the jacket (569 cm³) and sat 28 mm below the cooker handles, so the cooker was not held. The handle was drawn as one block through the cooker. | A flat ring cut from 4 mm steel plate (348 mm inside, 408 mm outside diameter) at the level of the handle undersides; each handle rests on it; the jacket clears the inner edge by 5 mm. The ring sits on the two holder arms (25 x 25 x 2 mm tube), one M8 bolt each. The handles are drawn outside the wall. | A flat ring is simpler to make than a rolled band and gives the handles a flat seat. The cooker drops in and lifts out without tools, as the concept intended. |
| C4 | The holder arms ended against the timber with no fixing. | Each arm rests on the top of its upright, flush with the outer face, and on the flat leg of a 40 x 40 x 4 mm angle bracket bolted to the upright's inner face; two M8 bolts. The uprights end at the arms (1,099 mm). | The arm bears on the timber and the bracket; nothing depends on screws in end grain. |
| C5 | Stand: braces butted into the rails and uprights with overlaps and no fixings; uprights stood on the rails with no fixing; the frame rails met at one level with no joint; a 75 mm castor was drawn 80 mm tall. | Side rails turned on edge (45 x 70 mm) and laid across the ends of the cross rails, two M8 bolts at each crossing. Uprights turned so they are 45 mm along the tilt axis and 70 mm across it, standing on the side rails with two galvanised angle brackets each. Braces lapped flat on the upright and side rail faces (the front brace outside, the back brace inside), one M10 bolt at each foot and one through both braces and the upright at the top. Castors at their real 102 mm mounting height, inboard of the side rails, each on four M8 bolts into the cross rail; the cross rails run 40 mm past the side rails so the crossing bolts are clear of the rail ends. | Every timber joint is face to face and bolted, so the stand comes apart into two side frames (6.0 kg each) and two cross rails with castors (3.4 kg each). With the upright and side rail both 45 mm wide, their outer faces line up and a brace can lie flat on both. |
| C6 | Dish frame: the ribs were drawn into the reflector sheet (36 cm³), their inner ends only touched the hub plate's edge and their outer ends stopped 10 mm short of the rim, with no fixings; a petal had nothing to rivet to on a rib standing on edge. | Ribs (20 x 3 mm, on edge) sit just behind the sheet. Each petal has a 12 mm flange folded down along both long edges; neighbouring flanges lie either side of a rib and one rivet goes through both flanges and the rib. Each rib's inner end stands on a 200 mm hub plate, 4 mm thick (was 150 x 6 mm) and its outer end meets the rim band, each joint held by a clip cut from 20 x 20 x 3 mm angle (24 clips, M5 bolts). The rim band is 25 x 4 mm (was 20 x 4 mm); each petal has two tabs riveted inside it. Ribs are at 15 degrees plus 30 degree steps, so none is under a rim stand-off. | Rivets need a face to grip; the flanges give one without changing the rib or the petal layout. The clips are the simplest bolted joint between a bar on edge and a flat plate or band. The 3 to 5 mm seam over each rib is what the photoreal model already shows. |
| C7 | The gnomon's target plate was drawn on the reflector face, overlapping the petals and ribs, with no fixing. | The target plate (120 mm, 3 mm aluminium) and its pin sit on a 40 x 40 x 4 mm angle bracket bolted to the outside of the rim band at the dish's lowest point, between two ribs. | Outside the rim it shades no reflector, it is reachable from the ground, and it bolts to steel. The pin stays parallel to the dish axis, so aiming is unchanged. |
| C8 | The power bank hung below the logger box, outside it (the BOM says it is inside), and the cable to the lid ran through the lid gland. No pressure transducer was drawn on the tee. | A bought IP65 box about 180 x 80 x 65 mm holds the board, display and power bank, screwed to the outer face of the right-hand upright below the lock stud. The cable leaves through a gland, runs along the top of the right holder arm and up to the transducer, now drawn on the tee, with plugs at the lid and the box so the lid comes off. The base thermocouple is held on the bare band by a stainless band clamp. | Completes BOM line 14 as described; the box sits below the lock stud and above the braces, and the plugs let the operator open the lid without cutting wires. |
| C9 | Assembly: with the yoke plates fixed to the dish, no order of assembly let the dish go between the uprights, because the yoke plates would have needed to slide down a 6 mm gap with no clearance. | The 2 mm PTFE thrust washer sets a 2 mm gap between each yoke plate and its axle plate. The build order fits one axle plate, lowers the dish (with its yoke plates) in from above, then slides the second axle plate down into the 8 mm space left, and pushes the axles in from outside. | A build order that works with two people and no lifting gear; the washer also makes the tilt smoother. |

*Table 2. Knock-on changes.*

| Item | Change | Reason |
| --- | --- | --- |
| Mass | Empty total 44.4 kg (was 41.0 kg) against the 45 kg of R16, 0.6 kg of margin, now taken from the model's parts rather than estimated. Largest piece 15.4 kg (the dish with its yoke plates), against 20 kg; the stand now comes apart, so the 19.4 kg one-piece stand of v0.2 is gone. | Steel clips, plates, brackets and bolts added; rim and hub slightly larger. |
| Optics | Absorbed power 663 W in the design case (was 669 W): the holder ring is wider than before and now counted in the ray trace with the handles. Cycle 80 min central (was 79), 109 min unfavourable (was 107). | Ring sized to carry the handles. |
| Stability | Tipping factor 1.38 at 15 degrees (was 1.30): the heavier tilting group and the slightly wider castor line help. R15 stays at risk. | Follows the model. |
| Lock | The tilting group (15.4 kg, centre of mass 321 mm from the axis) puts up to 45 N·m on the locks at 15 degrees (was 38 N·m for the dish alone). | The yoke plates now tilt with the dish and are counted. |
| Cost | Estimated cost of the constructable design USD 497 against the USD 450 value-engineering target (USD 47 over). BOM lines 1 to 5, 14, 16 and 17 respecified and repriced; no new lines. | Parts added for construction. |
| Drawings and documents | SCL-DWG-001 Rev P3; making sketches SCL-DWG-101 to 118 added; SCL-CAL-001 v0.3, SCL-REQ-001 v0.5 and SCL-PRC-001 v0.5 updated; build plan SCL-BLD-001 and register SCL-DEC-001 added. | Follows the model. |

*Table 3. Proposed for Amish; decided on 2026-10-02 as shown under each recommendation.*

| # | Question | Options | Recommendation |
| --- | --- | --- | --- |
| A1 | The R16 mass margin is now 0.6 kg (44.4 kg against 45 kg), on modelled parts and catalogue masses. | (a) accept and weigh the prototype at TRL 4; (b) take mass out now, for example 5 mm yoke plates and 20 x 20 mm holder arms (about 0.9 kg). | (a), with (b) ready if the weighed prototype is over. Accepted by Amish, 2026-10-02. |
| A2 | The tilt lock is a friction clamp (two star knobs), like the concept's lever on a slotted quadrant. A positive lock (a pin through holes at fixed elevations) would not slip, but sets the aim in steps. | (a) friction locks as modelled; (b) add a drop pin through a row of holes in the fan as a back-up. | (a) for the prototype, and check the slip torque at TRL 4; this is a pinch-point safety trade-off, so it is Amish's call. Changed in the recommendation to Amish and decided on 2026-10-02: (a) for aiming plus (b), a drop pin through a row of holes in the fan as a back-up stop, so a slip is limited to one hole; the pin is removed only if the TRL 4 slip test shows the locks holding at least twice the 45 N·m worst torque. |

## Consequences

- `design_state: constructable` in `project.yaml`. The build plan SCL-BLD-001 shows every component and step in pictures generated from the model (`cad/src/build_plan_media.py`).
- Requirement status: 14 met, 2 at risk (R4, R15), 1 not verifiable at TRL 3 (R1); R17 is reported against the value-engineering target (USD 47 over), not as met or not met (SCL-CAL-001 v0.3).
- The appearance model `cad/src/product_model.py` was rebuilt on the constructable design on 2026-10-02 and its render scenes exported; the photoreal renders (`media/render-*.png`), `media/card.png` and `media/social-preview.png` still show the concept and are to be redrawn on Amish's Mac.
- The lid-fitting method (SCL-DDR-001 item 5) was decided on 2026-10-02: the maker's lid is not drilled; a pressure canner sold with a factory gauge and relief valve is used, and the probe gland goes on an adapter plate on the vent stem that keeps a bore of 3 mm or more and leaves the overpressure plug untouched; a lid is drilled only with the maker's written approval. It was carried into the model, BOM, calculations and build plan on 2026-10-02 (SCL-CAL-001 v0.4, SCL-BLD-001 v0.3).
- With A2 decided, a drop pin on a lanyard each side now passes through the upright, a short slot in the axle plate and one of a row of holes in the yoke plate's fan; the lock slot moved from a 150 mm to a 140 mm radius to make room. With A1 accepted, the prototype is weighed at TRL 4; the margin is now 0.2 kg (44.8 kg).

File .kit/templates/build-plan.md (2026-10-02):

---
doc_id: PRJ-BLD-001
title: Project prototype build plan
project: Project name
doc_type: Build plan
version: "0.1"
status: Draft
date: YYYY-MM-DD
author: Amish Chadha
license: CERN-OHL-S-2.0
revisions:
  - version: "0.1"
    date: YYYY-MM-DD
    author: Amish Chadha
    change: First build plan; design made constructable
---

# Project prototype build plan

**Plan, not yet built.** How to build the first proof-of-concept prototype, component by component. Building and testing to it is TRL 4 work. Decisions still to be made are kept in the design decisions register (`docs/06-design-decisions.md`), not here.

## 1. What you are building

Every component, pulled apart and numbered in build order

One short paragraph: what the prototype is, how many components, which are made and which are bought, and the main ways they are made.

## 2. What changed to make it buildable

| Component | The concept had | The buildable design has | Why |
| --- | --- | --- | --- |

## 3. Making the components

### 3.1 Component name

Making sketch

**What it is and what it is made from.**

**How to make it.**

1. Mark out ...
2. Cut ...

**How it fits the parts next to it.**

Close-up of the joint

**Check before moving on.**

## 4. Putting it together

### Step 1: ...

Step 1

## 5. First checks

| Check | Requirement | How | Pass when |
| --- | --- | --- | --- |

## 6. Safety stops

## 7. Tools, skills and workspace

## 8. Where the numbers come from

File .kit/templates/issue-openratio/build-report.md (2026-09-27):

---
name: Build report
about: Tell us what happened when you built, printed or tested part of this design
title: "Build report: "
labels: build-report
---

This is a research and educational prototype, not a medical device. It is a TRL 3 concept and is not released for fabrication. If you build any part of it, you do so at your own risk. Reports help everyone.

**What you built** (part, sub-assembly or test)

**Materials, tools and settings**

**What worked**

**What did not work, with photos or measurements if you have them**

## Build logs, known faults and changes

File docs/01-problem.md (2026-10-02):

---
doc_id: SCL-PRB-001
title: SunClave problem statement
project: SunClave
doc_type: Problem statement
version: "0.4"
status: Draft
date: '2026-10-02'
author: Amish Chadha
license: CERN-OHL-S-2.0
revisions:
- version: "0.1"
  date: '2026-09-24'
  author: Amish Chadha
  change: Initial scaffold
- version: "0.2"
  date: '2026-09-25'
  author: Amish Chadha
  change: Populate to TRL 2 (users, context, constraints, out of scope, cited prior work, open questions)
- version: "0.3"
  date: '2026-09-25'
  author: Amish Chadha
  change: Apply SCL-DDR-001 (budget $450, altitude option B, backup heat) and correct the altitude figures from SCL-CAL-001
- version: "0.4"
  date: '2026-10-02'
  author: Amish Chadha
  change: First partner to approach, decided on 2026-10-02 (SCL-DEC-001)
---

# SunClave problem statement

Clinics without reliable electricity cannot run an electric autoclave, so reusable instruments are often boiled, soaked in chemicals or steamed in an unmonitored pressure cooker, and nobody can show afterward that a given load reached sterilizing conditions. SunClave aims to supply the heat from the sun and, just as important, a record of every cycle.

> **Safety:** SunClave is a research and educational prototype. It is not a medical device, has not been cleared or approved by any regulator, and must not be relied on to sterilize instruments used on patients. It concentrates sunlight to a burning intensity and generates pressurized steam at about 121 °C (250 °F).

## The problem

Steam under pressure is the standard way to sterilize heat-tolerant instruments. The CDC gives minimum exposure times of 30 min at 121 °C for wrapped instruments in a gravity-displacement sterilizer ([CDC, Table 7](https://www.cdc.gov/infection-control/hcp/disinfection-and-sterilization/steam-sterilization-cycle-times.html)), and IARC's WHO-aligned manual for low-resource clinics gives 20 min at 121 to 132 °C for unwrapped instruments and 30 min for small wrapped packs ([IARC colposcopy manual, chapter 14](https://screening.iarc.fr/colpochap.php?chap=14.php&lang=1)). WHO's reprocessing manual describes the whole cycle of cleaning, packing, sterilizing and monitoring that a clinic needs ([WHO, 2016](https://iris.who.int/handle/10665/250232)).

The energy is the first barrier. WHO and partners estimate that close to 1 billion people in low- and lower-middle-income countries are served by health-care facilities with no electricity or unreliable electricity; in sub-Saharan Africa about 15 % of facilities have no electricity at all and only about 40 % have a reliable supply ([WHO fact sheet, 2023](https://www.who.int/news-room/fact-sheets/detail/electricity-in-health-care-facilities)). A small electric autoclave draws 1.5 to 3 kW for an hour or more per cycle, far beyond a clinic's solar lighting system.

The evidence is the second barrier. A household pressure cooker on a fire can reach sterilizing conditions if instruments sit above the water and the cycle is long enough, but results depend on the vessel, its seal and the operator, and constant monitoring with biological indicators is recommended ([Baez, pressure cookers for clinical instruments](https://cdn.ymaws.com/sites/adint.site-ym.com/resource/resmgr/NewsArticles/Use_of_pressure_cookers_for_.pdf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)). Clinics rarely have a thermometer inside the vessel, let alone a record per load.

A third, less obvious barrier is altitude. A cooker regulated at 103.4 kPa (15 psi) above ambient reaches about 121.0 °C only at sea level (120.95 °C). At 1,800 m (Nairobi) the same cooker reaches only about 117.7 °C (SCL-CAL-001 gives the calculation), which is not a 121 °C cycle. The decided response (SCL-DDR-001 item 1) is a longer hold, recorded at its real temperature.

## Users and context

| User | Need | Context |
| --- | --- | --- |
| Nurse or clinical officer running a rural health post | Sterilize a small daily set of reusable instruments (delivery, suturing, dressing, minor procedure kits) without grid power or fuel | Health post or dispensary, 5 to 30 patients a day, one or two staff |
| Midwife at a maternity unit or birthing center | Sterile delivery kits for each birth, including at night from a stock sterilized in the day | Births at any hour; kits stored wrapped |
| Facility in-charge and district supervisor | Evidence that each load reached temperature and time, for audits and infection-control reviews | Paper registers today; periodic supervision visits |
| Dental or eye outreach team | Sterilize instruments at a temporary site for a few days | Mobile camps, school or church halls |
| Biomedical technician or local fabricator | Build, repair and calibrate the unit with local materials and tools | District workshop, hand tools, basic welding |

### Operating environment

- **Sun:** clear-sky direct normal irradiance (DNI) of 600 to 900 W/m² around midday in much of the tropics and subtropics in the dry season, with long cloudy or hazy spells in the rains ([Global Solar Atlas](https://globalsolaratlas.info/)). Concentrators use only direct sun, so an overcast day yields no cycles.
- **Altitude:** sea level to about 2,400 m; many East African facilities are at 1,000 to 2,000 m.
- **Climate:** ambient 10 to 40 °C, wind to 10 m/s, dust, occasional rain while a cycle runs.
- **Water:** clean water available but not always distilled; hard water scales vessels.
- **Supply chain:** aluminum household pressure cookers, steel tube, aluminum sheet and basic electronics modules are available in regional towns; certified medical parts are not.

## Constraints

- Garage-buildable prototype, $450 USD in parts (`project.yaml`; raised from $400 by Amish on 2026-09-25, SCL-DDR-001 item 2).
- Uses a commercially made pressure vessel rated for its working pressure. No homemade pressure vessel.
- Buildable and repairable by a district workshop with hand tools, a drill and simple welding or bolted joints.
- Operable by one trained person; movable by two.
- Every cycle is recorded automatically, independent of the operator's notes, with a pass or fail result.
- Research and educational prototype only: it must not be presented as a medical device or as a substitute for a certified sterilizer.

## Out of scope

- Regulatory clearance, certification or clinical deployment.
- Hollow, lumened or porous loads (textile packs, tubing, handpieces), which need active air removal that a pressure cooker cannot provide.
- Pre-cleaning and washer-disinfection; SunClave assumes instruments arrive cleaned.
- Heat storage for night-time or cloudy-day cycles (a possible later variant).
- Medical waste treatment.

## Prior work

- **Capteur Soleil solar autoclave (Kaseman et al., 2012).** A 2 m² semi-parabolic aluminum concentrator heated 14 L and 24 L All-American sterilizers above 121 °C for 30 min in all 27 trials, confirmed by thermometer, indicator tape and biological indicators. Heat-up averaged 93 to 183 min depending on the run ([AJTMH](https://www.ajtmh.org/view/journals/tpmd/87/4/article-p602.xml)). This is the closest precedent and shows the concept works; SunClave adds a smaller dish, a lower-cost cooker and an electronic cycle record.
- **Rice University nanoparticle solar autoclave (Neumann et al., 2013).** Light-absorbing nanoparticles in water generated steam directly under a Fresnel lens and passed sterilization tests ([PNAS](https://www.pnas.org/doi/10.1073/pnas.1310131110); [summary](https://sciencedaily.com/releases/2013/07/130722141552.htm)). It needs specialist materials that local workshops cannot make.
- **SK14 parabolic solar cooker.** A 1.4 m dish of reflective aluminum segments delivering about 700 W at 750 W/m², sold as a kit and widely used for cooking ([EG-Solar SK14](https://eg-solar.de/en/produkt/sk14/)). SunClave borrows its size and petal construction.
- **Pressure cookers as sterilizers.** Studies show household cookers can reach sterilizing conditions with a platform above the water and biological-indicator monitoring ([Baez](https://cdn.ymaws.com/sites/adint.site-ym.com/resource/resmgr/NewsArticles/Use_of_pressure_cookers_for_.pdf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)).
- **Small sterilizer standards.** EN 13060 defines small steam sterilizers, with type N cycles limited to unwrapped solid products ([EN 13060-3, type N](https://standards.globalspec.com/std/10364805/nen-en-13060-3)). SunClave's load limits follow the same logic, without any claim of compliance.
- **Review of solar-thermal autoclaves.** A 2021 review surveys collector types for autoclaves ([ResearchGate](https://www.researchgate.net/publication/352191747_Review_of_solar-thermal_collectors_powered_autoclave_for_the_sterilization_of_medical_equipment)).

## Open questions

- Which partner and first site? Decided by Amish on 2026-10-02 (SCL-DDR-001 item 12): the first candidate to approach is a university biomedical or global health engineering group with an established rural clinic partner in a sunny region below 2,400 m, for example through an Engineering World Health university chapter. Not yet agreed with any partner.
- How large is a typical daily load, and are packs wrapped or unwrapped? This sets vessel size and hold time.
- What is the site altitude? Above sea level a 103.4 kPa cooker cannot reach 121 °C; the decided extended hold (option B) grows from 30 min to about 63 min at 1,800 m for a wrapped load (SCL-CAL-001).
- Which backup heat source is available on cloudy days (wood, charcoal or LPG)? The same cooker on a stove, logged the same way, is decided (SCL-DDR-001 item 11).
- Who would own the cycle records, and in what form do supervisors want them (printed ticket, register entry, phone export)?

## User research and co-design

This design is for health workers in settings the author is not part of, so requirements must come from the people who will use it.

- [ ] Identify a local partner organization. First candidate to approach (decided 2026-10-02, not yet agreed): a university biomedical or global health engineering group with an established rural clinic partner in a sunny region below 2,400 m, for example through an Engineering World Health university chapter
- [ ] Run co-design sessions with intended users; record who, where and what was learned
- [ ] Validate load, cycle count, altitude and cost assumptions in the field
- [ ] Revise requirements (REQ) from findings before freezing the design

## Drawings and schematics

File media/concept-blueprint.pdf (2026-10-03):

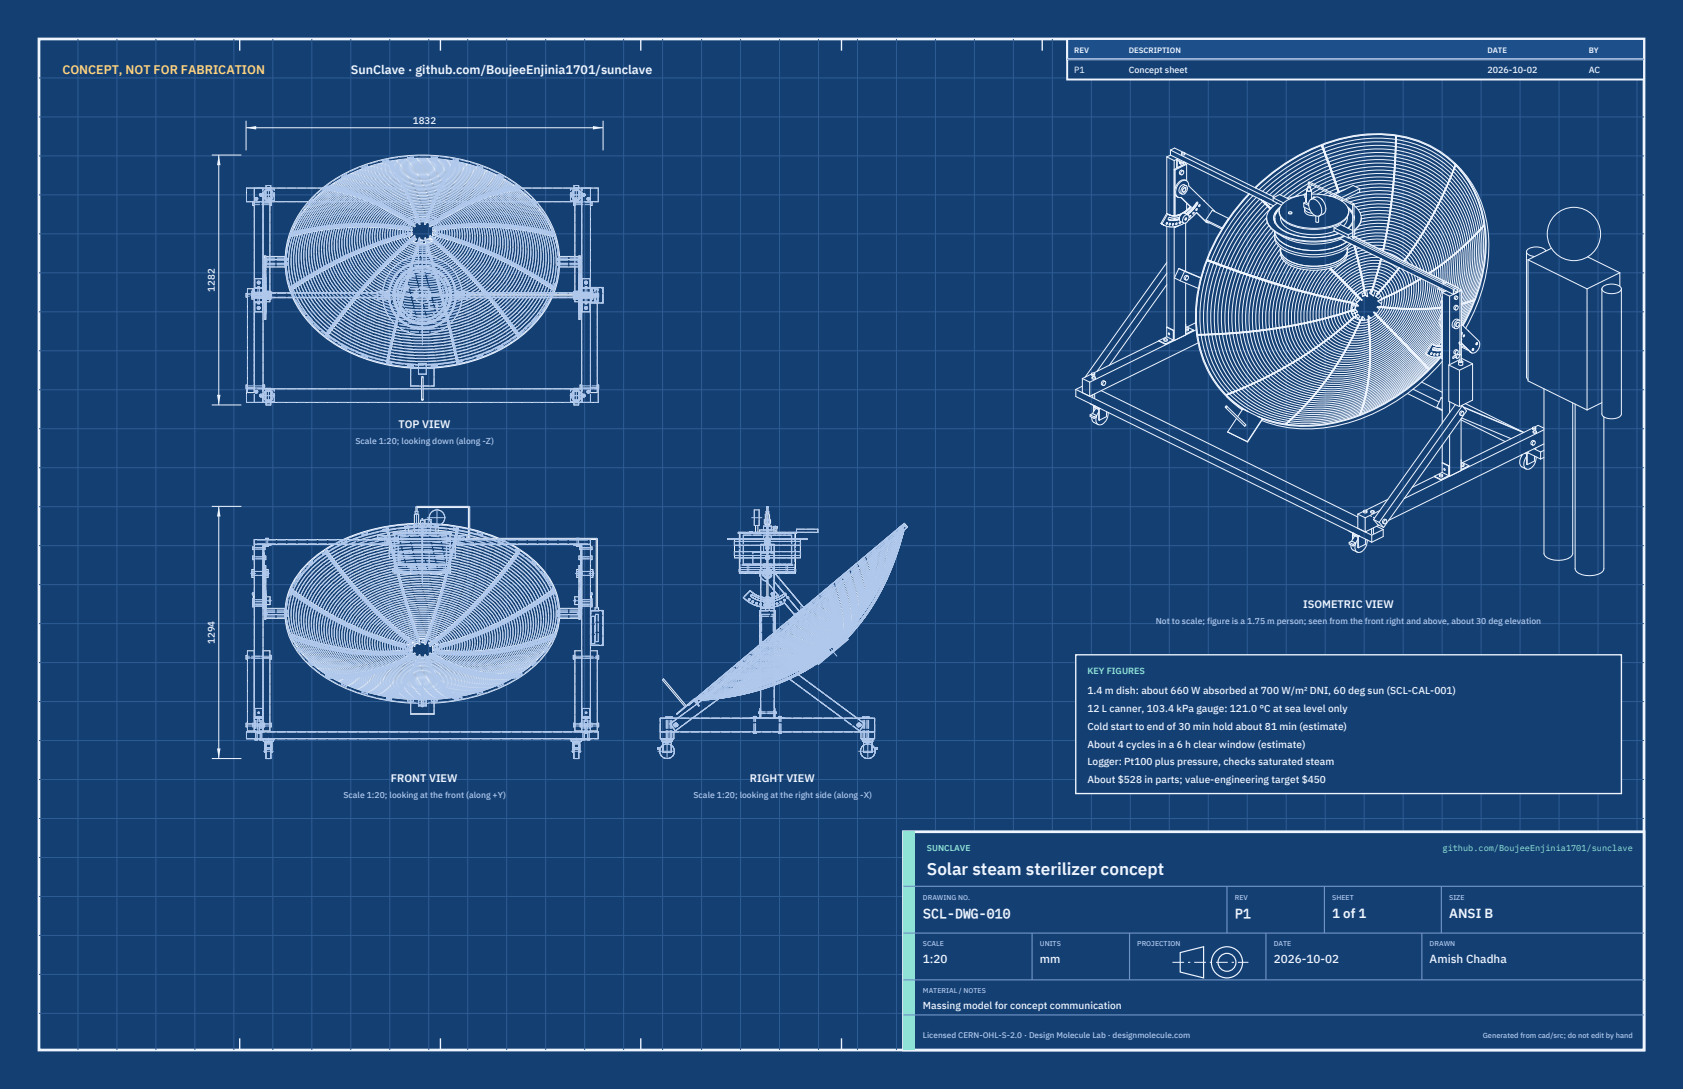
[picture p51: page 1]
CONCEPT, NOT FOR FABRICATION; SunClave · github.com/BoujeeEnjinia1701/sunclave; FRONT VIEW; TOP VIEW; RIGHT VIEW; ISOMETRIC VIEW; REV; DESCRIPTION; DATE; Concept sheet; SUNCLAVE; github.com/BoujeeEnjinia1701/sunclave; DRAWING NO. SCL-DWG-010; REV P1; SHEET 1 of 1; SIZE ANSI B; SCALE 1:20; UNITS mm; PROJECTION; DRAWN Amish Chadha; Licensed CERN-OHL-S-2.0 · Design Molecule Lab · designmolecule.com; Generated from cad/src; do not edit by hand

Scale 1:20; looking down (along -Z)

Not to scale; figure is a 1.75 m person; seen from the front right and above, about 30 deg elevation

KEY FIGURES
1.4 m dish: about 660 W absorbed at 700 W/m² DNI, 60 deg sun (SCL-CAL-001)
12 L canner, 103.4 kPa gauge: 121.0 °C at sea level only
Cold start to end of 30 min hold about 81 min (estimate)
About 4 cycles in a 6 h clear window (estimate)
Logger: Pt100 plus pressure, checks saturated steam
About $528 in parts; value-engineering target $450

Scale 1:20; looking at the front (along +Y)

Scale 1:20; looking at the right side (along -X)

Solar steam sterilizer concept

MATERIAL / NOTES
Massing model for concept communication

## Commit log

2026-09-24 Initial scaffold: standard open hardware layout, CERN-OHL-S v2 + MIT licenses
    Claude-Session: https://claude.ai/code/session_01XuhhSU4W6fYhgCfURbrkut
    [bom.csv]
2026-09-25 Adopt portfolio kit v1.3.0: session commands, scale figure, 3D viewer, flow diagrams
    Adds .claude/commands (/populate, /advance-trl3, /rein-in, /refresh-media)
    so every Claude Code session starts from the standard prompts, and extends
    concept media with a 1.75 m scale figure, an interactive glTF viewer and
    system or energy flow diagrams. TRL cap 3 unchanged.
    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
2026-09-25 Kit v1.3.1: renderer fixes from the TremorTrace pilot
    Context scale parts for small objects, cutaway exclusions, and text
    labels in flow diagrams.
    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
2026-09-25 Populate sunclave to a strong TRL 2 with concept media (overnight batches 4 and 5)
    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
    [bom.csv]
2026-09-25 Advance sunclave to TRL 3 (batches 5 and 6)
    Decisions approved by Amish 2026-09-25 recorded in DDR-001. TRL 4 is on hold.
    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
    [bom.csv, results.csv, sunclave-assembly.step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]
2026-09-26 Accept all recommendations (DDR-002), switch footer to designmolecule.com, add README write-up with new inspiration point
    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
    [bom.csv, results.csv, sunclave-assembly.step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]
2026-09-27 Product appearance model and photoreal renders
    Adds cad/src/product_model.py (appearance model for renders only, all main
    dimensions from model.py) and Blender renders in media/render-*.png,
    captioned with the project, repository and viewing direction. README leads
    with the product render; trl stays 3.
    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
2026-10-01 Image quality pass: legible exploded views, flow diagrams and drawing sheets
    Kit 1.6.1 image layout: the parts list sits in its own column, number bubbles sit on visible parts and never overlap, small parts get a leader, pictures are cropped to the subject, flow labels keep numbers with their units, and sheet captions and the revision table no longer overprint. Concept images, blueprint and general arrangement sheet regenerated; repo-specific labels moved clear of other text and lines.
2026-10-02 Kit 1.7.0: constructable design, illustrated build plan and design decisions register
    The design is now constructable: every part can be made and fits its neighbours, with each change recorded in a Design for construction decision record (made under Amish's 2026-09-30 instruction; ope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
    FlexHand also credits Dr. Geeti Chadha as a contribut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
    [bom.csv, results.csv, sunclave-assembly.stl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]
2026-10-02 Record Amish's approval of the open-decision recommendations
    Amish approved the recommendation on every open decision in the design decisions register ("i approve your recommendations for all 555 open decisions.", 2026-10-02). Each decision is moved to Decisio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
2026-10-03 Carry approved follow-ups into the design and redo photoreal renders
    Amish approved the follow-up actions from the open-decision sign-off ("APPROVED CHANGES, COMPLETE THESE", 2026-10-02), the design-for-construction change tables in ten repos, the last wave's open dec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
    [bom.csv, results.csv, sunclave-assembly.stl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]
2026-10-03 Record Amish's 2026-10-03 decisions; FlatTrike fork and PotPress guard fixes
    Amish, 2026-10-03: "PalletPilot - i accept it"; "FlatTrike - i accept your design recommendation, proceed and execute the solution for fork direction or caster"; "PotPress - move forward with the four guard fixes. I accept the cost."; "GravitySort - i accept your recommendation"; "TIght Margins - i accept the margins"; "Cost over target - i accept all the cost variations and overruns". FlatTrike knuckle forks turned to trail (35 mm trail); PotPress finer mesh, small-hole plates, top beam and crank bracket covers, ISO 13857 desk check now met on paper. Registers, requirements, drawings, pictures, renders and PDFs upd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

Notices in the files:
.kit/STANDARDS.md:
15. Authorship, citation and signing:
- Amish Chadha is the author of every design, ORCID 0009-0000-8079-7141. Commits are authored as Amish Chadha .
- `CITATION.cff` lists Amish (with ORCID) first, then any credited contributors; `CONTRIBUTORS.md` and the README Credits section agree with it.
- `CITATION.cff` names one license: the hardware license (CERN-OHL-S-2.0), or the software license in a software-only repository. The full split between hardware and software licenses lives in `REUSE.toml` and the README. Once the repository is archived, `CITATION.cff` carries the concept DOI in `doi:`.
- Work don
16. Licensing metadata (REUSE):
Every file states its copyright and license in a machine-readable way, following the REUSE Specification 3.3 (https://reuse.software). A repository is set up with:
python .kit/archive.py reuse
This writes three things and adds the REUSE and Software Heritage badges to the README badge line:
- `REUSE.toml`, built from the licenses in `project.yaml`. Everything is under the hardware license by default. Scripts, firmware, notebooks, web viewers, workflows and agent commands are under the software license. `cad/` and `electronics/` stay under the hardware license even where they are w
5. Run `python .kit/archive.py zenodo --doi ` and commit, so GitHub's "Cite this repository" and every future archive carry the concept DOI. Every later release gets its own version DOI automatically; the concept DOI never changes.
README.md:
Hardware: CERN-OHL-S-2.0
